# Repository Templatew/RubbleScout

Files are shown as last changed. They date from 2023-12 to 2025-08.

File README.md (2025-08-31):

e

# RubbleScout: *"Navigating Chaos, Saving Lives"*

## Welcome to the Future of Search and Rescue

RubbleScout is a semi-autonomous robot designed to enhance search and rescue operations in disaster-stricken environments by utilizing advanced detection and navigation technologies.

## Project Overview

At this stage, RubbleScout is taking shape both in theory and in practice. 

## Gallery

_ANA2206-Enhanced-NR
_ANA2205-Enhanced-NR
_ANA2209-Enhanced-NR

https://github.com/Templatew/RubbleScout/assets/96289463/7052bb44-568c-42eb-913e-73d9d9e173d0

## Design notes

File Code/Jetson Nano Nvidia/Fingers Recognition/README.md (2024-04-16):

# Integration Guide for Finger Counting Project

## Loading the Jupyter Notebook on Jetson Nano
To initiate the finger counting system, you'll need to start by loading the provided Jupyter Notebook on your Jetson Nano. This notebook contains the necessary code to interface with the pretrained AI model and process the image data in real-time.

Follow these steps to load the notebook:
1. Power on your Jetson Nano and open the terminal.
2. Navigate to the directory containing the Jupyter Notebook.
3. Run the following command to start the Jupyter Notebook server:

`sudo docker run --runtime nvidia -it --rm --network host --volume ~/nvdli-data:/nvdli-nano/data --volume ~/notebooks:/nvdli-nano/notebooks --device /dev/video0 --device /dev/gpiochip0 --privileged nvcr.io/nvidia/dli/dli-nano-ai:v2.0.2-r32.7.1`

4. Open your web browser and enter the URL provided by the Jupyter server to access the notebook.

## Loading the Pretrained AI Model
Once the Jupyter Notebook is up and running, you'll need to load the pretrained AI model `V3.pth` to perform the finger counting. The notebook will have cells dedicated to this task—ensure you execute them to load the model into memory.

## Uploading Code to Arduino Uno
The next step involves uploading the control code to your Arduino Uno. This code is responsible for receiving the finger count and translating it into a binary representation on the LEDs.

To upload the code:
1. Connect your Arduino Uno to your PC via a USB cable.
2. Open the Arduino IDE and load the provided Arduino script.
3. Select the correct board and port from the Tools menu.
4. Click the Upload button to program your Arduino Uno with the script.

## Wiring Schema
A detailed wiring schema is provided in the `wiring` directory. Refer to this schema for connecting the LEDs to your Arduino Uno, and for establishing the I2C communication between the Jetson Nano and Arduino Uno.

Ensure the following connections are made according to the schema:
- Connect SDA and SCL from the Jetson Nano to the corresponding SDA (A4) and SCL (A5) pins on the Arduino Uno.
- Ground connections must be common between both devices.
- If necessary, use pull-up resistors on the SDA and SCL lines, and ensure any required level shifting between 3.3V and 5V logic levels is in place to protect your devices.

After setting up the hardware according to the wiring schema, your system should be ready for a test run. Ensure you follow the instructions closely to avoid any damage to the components due to incorrect wiring or voltage levels.

## Gallery

https://github.com/Templatew/RubbleScout/assets/96289463/1811614b-35ff-42c6-a526-842b8b7e4687

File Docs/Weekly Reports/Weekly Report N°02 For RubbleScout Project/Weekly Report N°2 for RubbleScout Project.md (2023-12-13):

# Weekly Report N°2 for RubbleScout Project
School year 2023-2024

## Project Overview
- **Title:** RubbleScout
- **Tagline:** "Navigating Chaos Saving Lives"
- **Student:** Lorenz CAZAUBON
- **Supervisor:** Pascal MASSON
- **Institution:** Ecole Polytechnique Universitaire de Nice Sophia-Antipolis, Robotics Specialty (Autonomous Systems)
- **Location:** 930 route des Colles, 06410 BIOT France

## Session Activities
- **Lamp Circuit Examination:**
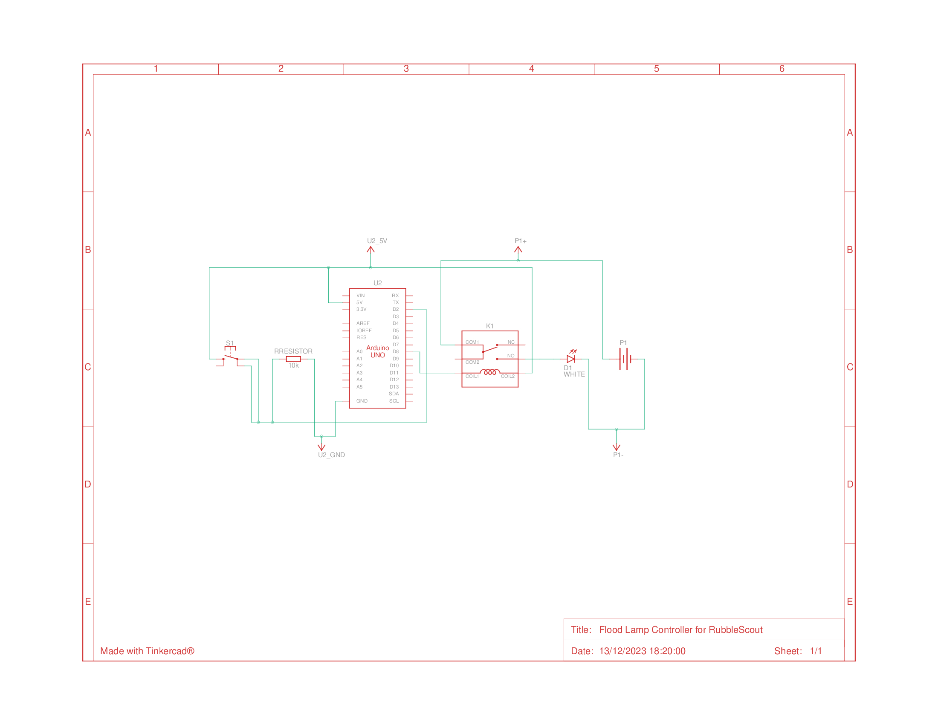
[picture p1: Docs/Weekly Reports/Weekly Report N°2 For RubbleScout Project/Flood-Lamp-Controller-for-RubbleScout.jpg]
  - Detailed review of the circuit powering the lamp. 
  - Identified the inability to vary lamp brightness using PWM due to unknown electronic components.
  - Implemented a relay circuit for on/off functionality without variable brightness.

- **PWM and Lidar Progress:**
  - Spent time seeking a solution for PWM, which was unsuccessful.
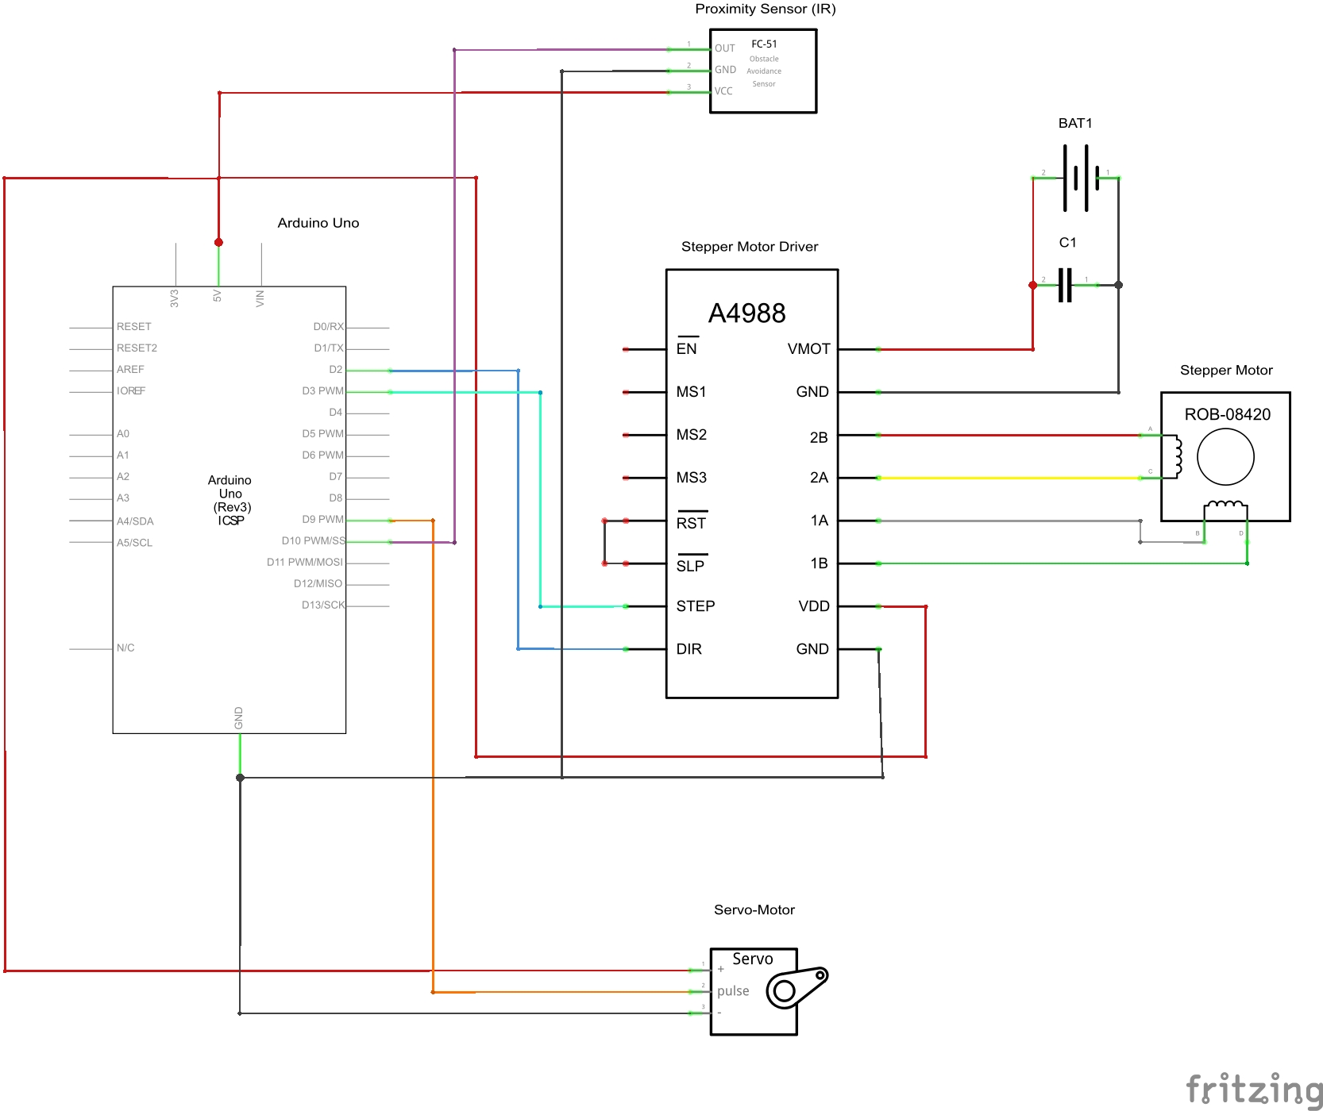
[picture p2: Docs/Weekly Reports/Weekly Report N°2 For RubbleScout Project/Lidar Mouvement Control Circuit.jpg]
Circuit SVG
  - Designed a circuit for controlling the Lidar's movements. 

## Plans for Next Session
- Intend to complete 3D drawings of the Lidar motion controller using CAD software.
- Aim to print and test the parts in the next session.
- Anticipate receiving the robot chassis for starting basic mechanics work.

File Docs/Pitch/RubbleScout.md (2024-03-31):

e
# RubbleScout Project Overview

## Introduction
This document serves as a brief presentation of the RubbleScout robot project for review and assistance from the faculty.

## Student Name
- Lorenz CAZAUBON

## Robot Name
- RubbleScout

## Objective
RubbleScout is designed as a semi-autonomous robotic system aimed at aiding search and rescue operations through 3D environmental scanning and object detection in disaster-stricken areas.

## Technical Synopsis
RubbleScout is built on a tracked platform equipped with a suite of sensors including LiDAR for 3D scanning, ultrasonic for obstacle detection, and cameras for visual input. The core processing unit is an NVIDIA Jetson Nano, which handles data processing and autonomous decision-making, supported by an ESP32 microcontroller for managing sensor integration and actuation.

## State Machine Overview
RubbleScout's software operates on a state machine with states such as Initialization, Standby, Scanning, and Data Transmission. Transitions between states are managed based on sensor inputs and operational modes.

## Hardware & Software Architecture
The robot features a modular architecture allowing for scalability and maintenance. The hardware includes motor drivers, power management, and sensor modules, while the software architecture is designed for real-time processing and modular updates.

### Architecture
- The robot's architecture comprises three primary layers:
  - **Sensing Layer:** LiDAR, ultrasonic sensors, and cameras for environment perception.
  - **Processing Layer:** NVIDIA Jetson Nano for high-level processing and ESP32 for low-level control and sensor integration.
  - **Actuation Layer:** Electric motors for movement and a servo motor for LiDAR scanning.

- [Link to Wiring Diagram](https://github.com/Templatew/RubbleScout/blob/main/Docs/Wiring/ESP32/Schematic_RubbleScout_2024-02-16.pdf)

### Code Overview
The software is developed using C++ on the ESP-IDF framework for real-time operations and Python on the Jetson Nano for data processing and machine learning tasks.

- [Link to Code Documentation](https://github.com/Templatew/RubbleScout/blob/main/Code/Main/README.md)

## Usage of NVIDIA Jetson Nano
- The Jetson Nano serves as the brain of RubbleScout, responsible for processing sensor data, creating 3D maps of the environment, and executing autonomous navigation algorithms. Potential uses also include survivor detection via machine learning and integration with other IoT devices for expanded capabilities.

## Risk Assessment
Identified risks include system malfunctions, electrical failures, and sensor inaccuracies. Mitigation strategies involve redundant design, rigorous testing, and real-time system monitoring.

## Recent Progress
- Successfully conducted the first LiDAR scan with data stored on an SD card.
- Transitioned to ESP-IDF for improved performance.
- Implemented a new DC-DC converter to prevent power issues.

## Supporting Materials
- [Link to the Code Repository](https://github.com/Templatew/RubbleScout/tree/main/Code)
- [Link to the Weekly Reports](https://github.com/Templatew/RubbleScout/tree/main/Docs/Weekly%20Reports)

## **Gallery**

https://github.com/Templatew/RubbleScout/assets/96289463/867a7651-68fa-45cb-8242-6cb173693c5a

https://github.com/Templatew/RubbleScout/assets/96289463/f9fa39b1-5d0c-4065-bb0d-41c5539a41e1

https://github.com/Templatew/RubbleScout/assets/96289463/a6dde0ae-bb52-4444-9256-39dd32141298

*This presentation is for academic review purposes*

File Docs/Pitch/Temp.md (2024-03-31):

# RubbleScout Project Presentation

## Student Name
- Lorenz Cazaubon

## Robot Name
- RubbleScout

## Objective of the Robot
- The primary objective of RubbleScout is to provide a semi-autonomous robotic solution for search and rescue operations within disaster-struck environments. RubbleScout is designed to navigate through rubble and challenging terrains, identify survivors, and provide real-time data to rescue teams, thereby enhancing the safety and efficiency of rescue missions.

## Technical Elements
### System Synopsis
- RubbleScout is built on a robust tracked platform, allowing for stable movement across varied terrains. The core of the system is the ESP32 microcontroller for control and the NVIDIA Jetson Nano for advanced processing tasks such as sensor data analysis and autonomous decision-making.

### State Machine
- The robot operates in several states:
  - **Idle:** Waiting for commands.
  - **Manual Control:** Direct control through user input.
  - **Auto Navigation:** Autonomous movement and obstacle avoidance. *(Not ready yet)*
  - **Scan Mode:** LiDAR-based 3D environment mapping.
  - **Data Transmission:** Sending collected data to the base station.
  
### Architecture
- The robot's architecture comprises three primary layers:
  - **Sensing Layer:** LiDAR, ultrasonic sensors, and cameras for environment perception.
  - **Processing Layer:** NVIDIA Jetson Nano for high-level processing and ESP32 for low-level control and sensor integration.
  - **Actuation Layer:** Electric motors for movement and a servo motor for LiDAR scanning.

### Code Overview
- The software is developed using C++ on the ESP-IDF framework for real-time operations and Python on the Jetson Nano for data processing and machine learning tasks.
More about the code [here](https://github.com/Templatew/RubbleScout/tree/main/Code)

## Usage of NVIDIA Jetson Nano
- The Jetson Nano serves as the brain of RubbleScout, responsible for processing sensor data, creating 3D maps of the environment, and executing autonomous navigation algorithms. Potential uses also include survivor detection via machine learning and integration with other IoT devices for expanded capabilities.

## **Gallery**

https://github.com/Templatew/RubbleScout/assets/96289463/867a7651-68fa-45cb-8242-6cb173693c5a

https://github.com/Templatew/RubbleScout/assets/96289463/f9fa39b1-5d0c-4065-bb0d-41c5539a41e1

https://github.com/Templatew/RubbleScout/assets/96289463/a6dde0ae-bb52-4444-9256-39dd32141298

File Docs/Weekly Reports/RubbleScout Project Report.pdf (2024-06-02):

Robotics,
Autonomous systems

# RubbleScout Project Report

School year 2023-2024

RubbleScout,

## "Navigating Chaos, Saving Lives"

## Student: Lorenz CAZAUBON

## Supervisor: Pascal MASSON

Polytech Nice Sophia, robotics speciality (autonomous systems)

930 route des Colles, 06410 BIOT, France

## Table of Content

1. Introduction | 2
2. Architecture | 3
3. Algorithm | 4
4. Project Cost | 4
5. Issues and Solutions | 5
6. Conclusion and Future Work | 5
7. Appendix | 7

### 1. Introduction

RubbleScout is a semi-autonomous robot designed to enhance search and rescue operations in disaster-stricken environments. The primary goal is to reduce risks for rescuers and speed up interventions by providing accurate data on affected environments.

Project Goals:

- Reduce Risks: Minimise the exposure of rescuers to dangerous and unstable conditions.
- Accelerate Interventions: Improve the efficiency and speed of search and rescue operations.
- Provide Accurate Data: Offer precise and reliable information about the disaster area to aid in decision-making.

Main Applications:

- 3D Mapping: Create detailed maps of disaster-stricken areas to assist in navigation and planning.
- Obstacle and Survivor Detection: Identify obstacles and detect survivors in the debris to facilitate rescue efforts.

### 2. Architecture

The following schematic illustrates the overall architecture and key components of the RubbleScout project. The system is centered around the ESP32 microcontroller, which interfaces with various sensors and actuators to perform the necessary functions. For detailed wiring connections, please refer to the appendix.

Main Components:

ESP32: The central microcontroller responsible for processing data and controlling the system.
Lidar + Servo and Stepper Motor: Used for distance measurement and 3D mapping. Jetson Nano + Camera: Planned for future implementation, responsible for advanced processing tasks like video streaming and object recognition.
SD Card Reader: Data logging.

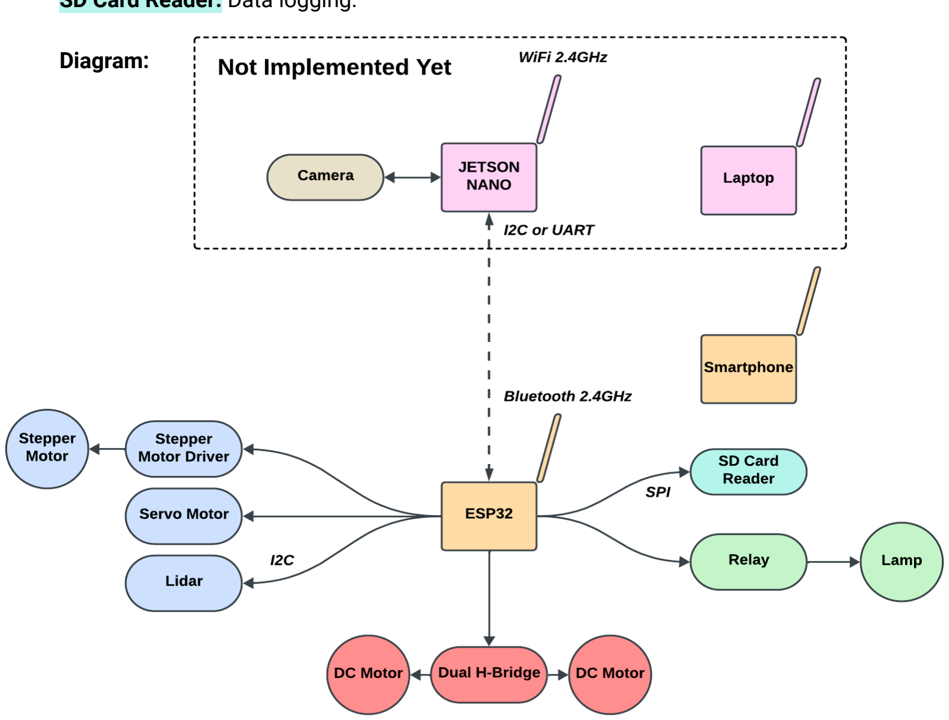
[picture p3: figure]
Diagram:

Note: The complete wiring schematic is included in the appendix for further reference.

### 3. Algorithm

The functionality is divided into different tasks managed by the ESP32 microcontroller.

The state machine for RubbleScout defines the different operational states of the robot and the transitions between these states.

This simplified diagram provides an overview of the key states and transitions:

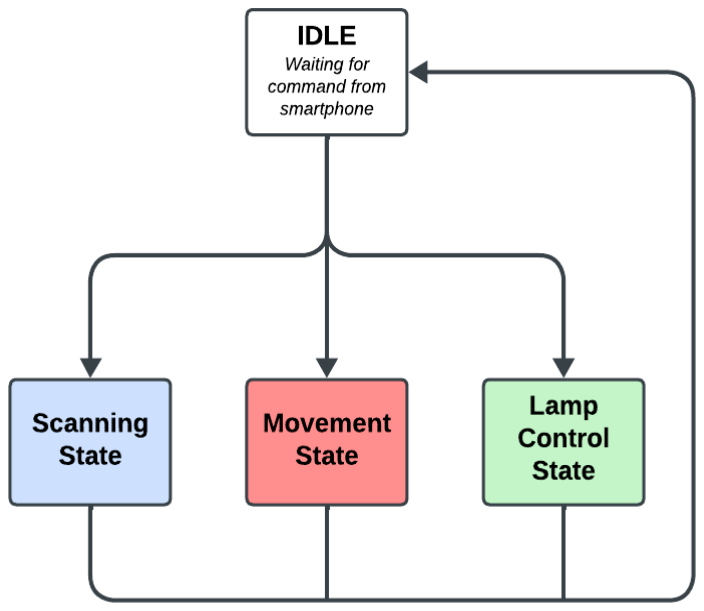
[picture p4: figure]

Note: The complete state machine diagram is included in the appendix.

### 4. Project Cost

In total I worked around 200 hours on the project (including 72 hours in the project session), and at an hourly rate of 23.75€, that works out at 4 750€ for the labour involved.

The total estimated cost is therefore 6 000€.

Component | Cost (€)
3D Scan Module | 430
Chassis + Motors | 180
Jetson + Camera | 290
ESP32 + SD | 40
Battery + Buck | 70
Lamp + Relay | 30
Building Materials | 120
Miscellaneous | 90
Total | 1 250

### 5. Issues and Solutions

Problem:
Power Supply Overload
Solution:
Replaced the LDO with a Buck Converter, which is more efficient and capable of handling higher power loads without overheating.

Problem:
The Arduino Uno microcontroller was unable to handle the computational demands of the project, particularly for the 3D scanning task which required more processing power and memory.
Solution:
Upgraded to an ESP32 microcontroller, which offers dual-core processing, integrated Bluetooth and Wi-Fi, and greater speed and memory capacity.

Problem:
The initial code implementation was too slow, causing delays in data processing and system responsiveness.
Solution:
Implemented multithreading using the ESP-IDF (Espressif IoT Development Framework) to run tasks in parallel, significantly improving the speed and efficiency of the system.

### 6. Conclusion and Future Work

RubbleScout has successfully achieved several key milestones:

3D Scanning: The system can perform 3D scans of its environment using Lidar, servo motors, and stepper motors. The data collected is stored on an SD card for further analysis.
Basic Movement: The robot can be controlled via a smartphone using Bluetooth, allowing for precise movement control.
Lamp Control: The system includes a relay-controlled lamp, which can be turned on and off remotely to provide illumination in dark environments.

However, some aspects of the project are still in development:

Jetson Nano Integration: The advanced computational capabilities of the Jetson Nano, such as video streaming, object recognition, and autonomous navigation, have not been fully implemented.

Future Work

To fully realize the potential of RubbleScout, the following developments are planned:

Integration of Jetson Nano:

-Implement video streaming and real-time processing for object and person recognition.
-Develop and integrate advanced navigation algorithms to enable autonomous operation.

Addition of New Sensors:

Integrate additional sensors such as temperature, gas, and humidity sensors to provide more comprehensive environmental data.

Long-Range Communication:

Implement long-range communication protocols (e.g., ELRS, CROSSFIRE) to extend the operational range of the robot in disaster-stricken areas.

Robustness and Durability:

Enhance the physical design of the robot to withstand harsh conditions in disaster environments, including shock absorption and waterproofing.

Conclusion:

RubbleScout represents a significant step forward in improving search and rescue operations. With further development and enhancements, it has the potential to become a vital tool for rescuers, providing them with the necessary data and capabilities to save lives more effectively and safely.

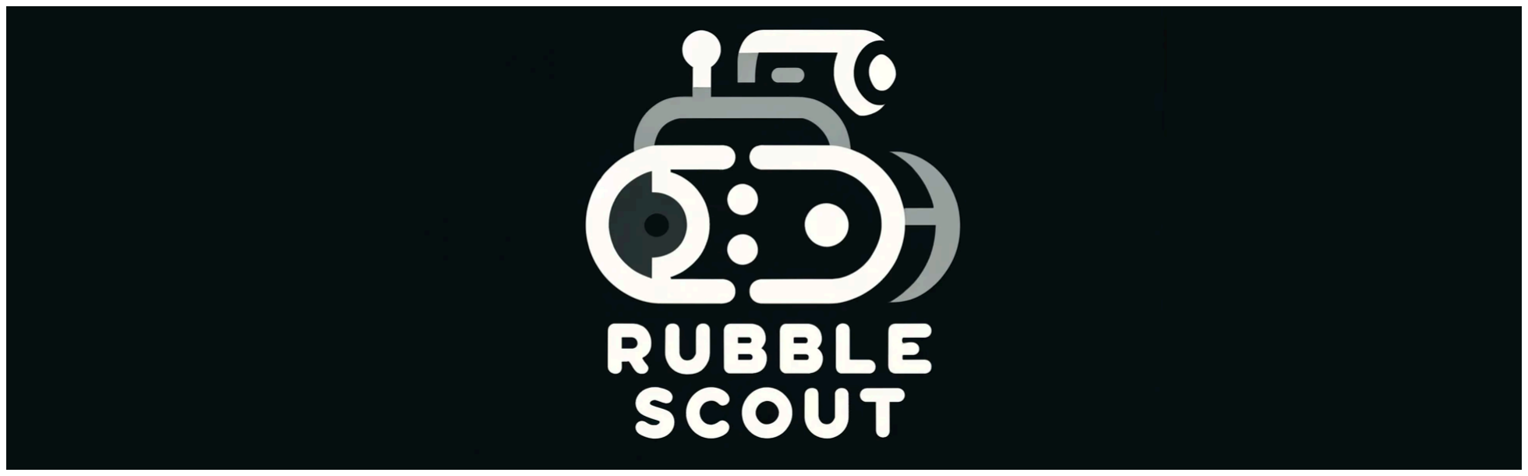
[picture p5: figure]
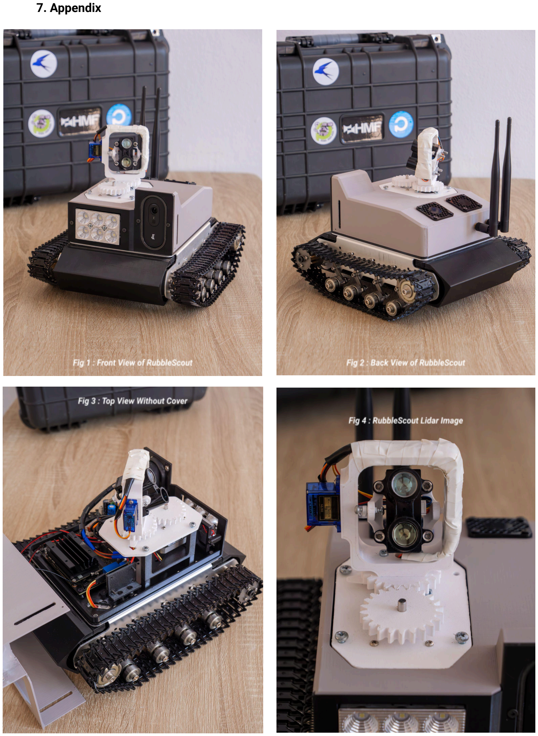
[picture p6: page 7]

### 7. Appendix

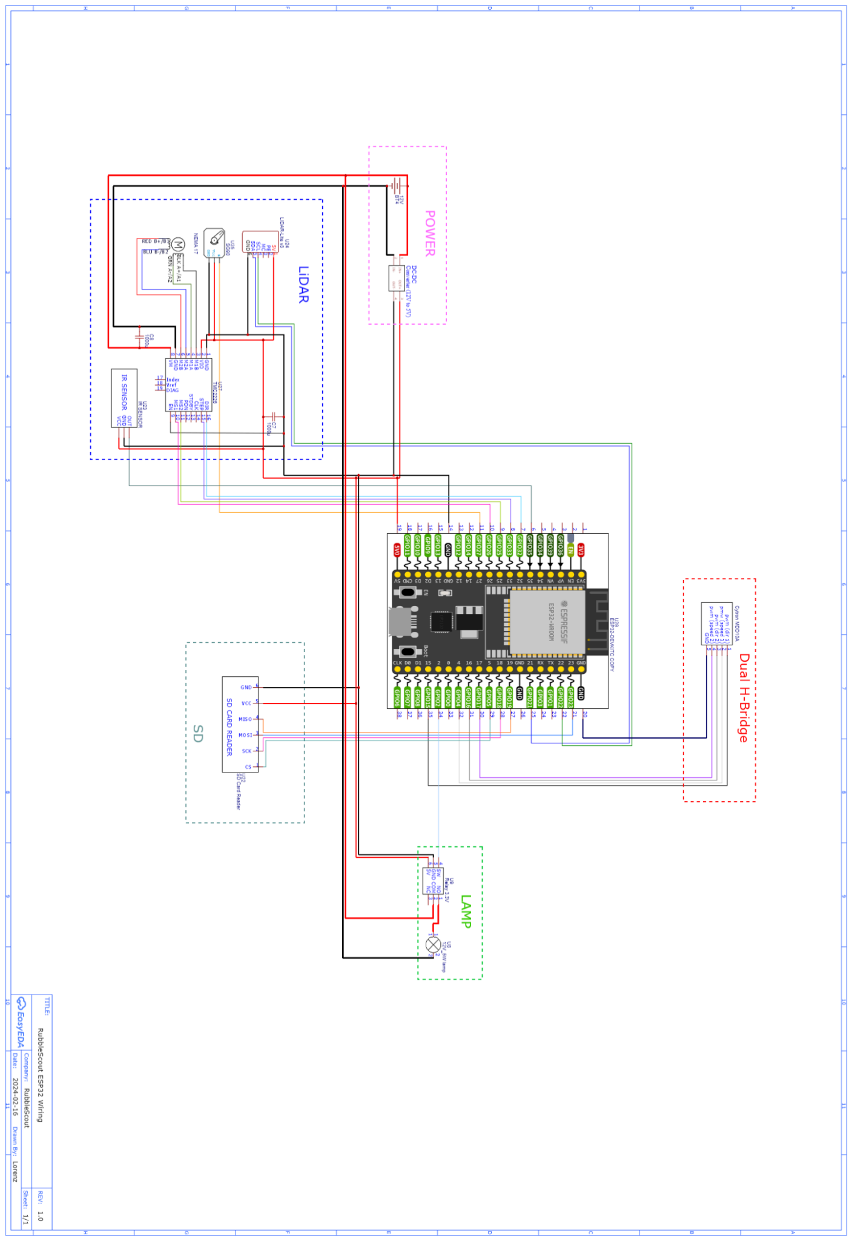
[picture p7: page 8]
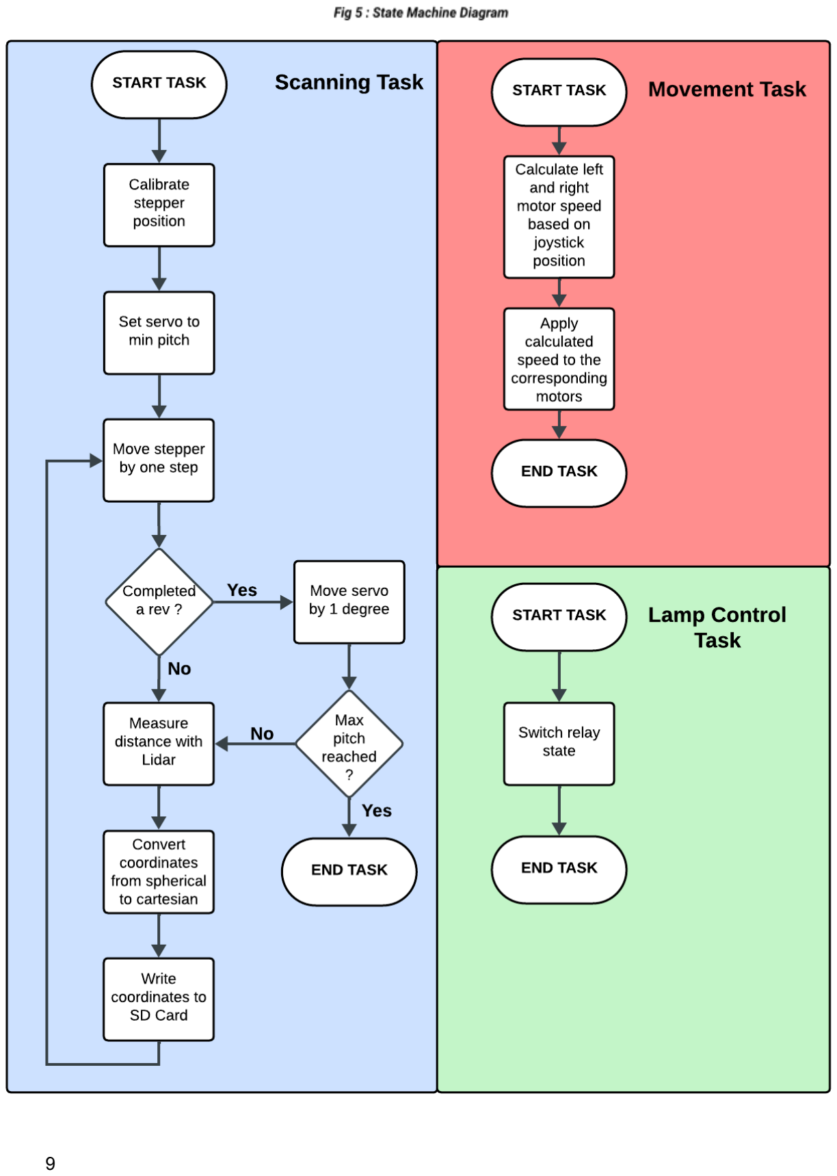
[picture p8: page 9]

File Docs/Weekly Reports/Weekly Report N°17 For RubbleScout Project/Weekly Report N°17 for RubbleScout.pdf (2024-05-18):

Robotics,

### Autonomous systems

# Weekly Report N°17 for

### School year 2023-2024

RubbleScout,

## "Navigating Chaos, Saving Lives"

## Student: Lorenz CAZAUBON

## Supervisor: Pascal MASSON

Ecole Polytechnique Universitaire de Nice Sophia-Antipolis, robotics speciality (autonomous systems)

930 route des Colles, 06410 BIOT, France

Objectives:

- Complete the design of new 3D parts in the CAD software for the updated RubbleScout robot assembly.

Activities Undertaken:

### 1. Completion of CAD Design:

- Finished designing all the new 3D parts in the CAD software, integrating the new functionalities and components:
- NVIDIA Jetson Nano mount
- multiple 40 mm fan housing for improved cooling
- PETG-based battery protection
- Reinforced wire connections for the ESP
- Mount for the Logitech C505e camera
- 12V lamp housing with relay control
- Aesthetic magnetic covers and other enhancements

### 2. Review and Refinement:

- Conducted a thorough review of the CAD designs to ensure all components fit together seamlessly.
- Made adjustments to optimize the layout and functionality, ensuring ease of assembly and maintenance.

Results and Observations:

- Design Completion: Successfully completed the CAD design phase, creating detailed models for all new parts.
- Enhanced Integration: The designs effectively incorporate the new components, promising improved performance, safety, and aesthetics for the RubbleScout robot.
- Preparations for Prototyping: The detailed CAD models are now ready for the next phase, which involves 3D printing and physical testing.

Next Steps:

- 3D Printing: Begin the process of 3D printing the newly designed parts.
- Test Fit and Assembly: Once printed, test fit all parts to ensure proper alignment and functionality.
- Iterative Refinement: Based on the test fitting results, make any necessary adjustments to the CAD models and reprint as needed.

2

Reflections:

This session marks a significant milestone in the redesign of RubbleScout, transitioning from conceptual planning to tangible design completion. The detailed CAD models set the stage for the next phase of development, where physical testing will validate the improvements and guide further refinements. The anticipation of seeing these new parts come to life and integrating them into the robot is high, as it promises to bring substantial advancements in RubbleScout's capabilities and usability.

3

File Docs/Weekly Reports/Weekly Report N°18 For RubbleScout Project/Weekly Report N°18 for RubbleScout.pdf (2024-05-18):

Robotics,

### Autonomous systems

# Weekly Report N°18 for

### School year 2023-2024

RubbleScout,

## "Navigating Chaos, Saving Lives"

## Student: Lorenz CAZAUBON

## Supervisor: Pascal MASSON

Ecole Polytechnique Universitaire de Nice Sophia-Antipolis, robotics speciality (autonomous systems)

930 route des Colles, 06410 BIOT, France

Objectives:

- Test fit the newly printed 3D parts for the RubbleScout robot.
- Identify necessary adjustments to the parts for enhanced functionality.

Activities Undertaken:

### 1. Test Fitting of 3D Printed Parts:

- Assembled the newly printed 3D components, including mounts for the NVIDIA Jetson Nano, the camera, and the lamp, along with the battery protection and magnetic covers.
- Evaluated the fit and alignment of each part within the robot's chassis.

### 2. Identification of Adjustments:

- Noted the need for modifications such as:
- Drilling proper holes for antenna integration to improve communication range.

Results and Observations:

- Fit and Function: Most parts fit well, but a few require adjustments for optimal functionality and integration.
- Cooling Requirements: The need for additional cooling for the lamp was identified during the test, prompting the decision to add a 40mm fan to this component.

Next Steps:

- CAD Adjustments: Update the CAD designs to incorporate the identified modifications, such as antenna holes and correct fan sizes.
- Reprint and Retest: Print the modified parts and conduct another test fit session to ensure all adjustments meet the project's requirements
- Develop Control Software: Begin coding a comprehensive control interface that allows user interaction with all robot functionalities, focusing initially on manual controls.
- Plan for Autonomous Functionality: Outline the steps necessary to implement autonomous operations, which will likely involve integrating sensor data with decision-making algorithms.

2

Reflections:

This session was crucial for validating the physical aspects of the latest design updates. The insights gained from test fitting are invaluable, directing specific modifications that will enhance the overall functionality and reliability of RubbleScout. Looking ahead, the focus will shift towards developing a user-friendly control interface, which will be a significant step towards achieving a fully operational prototype. The subsequent challenge will be to tackle the autonomous capabilities of the robot, marking a pivotal phase in the project that will test the integration of hardware and software to achieve independent operation.

3

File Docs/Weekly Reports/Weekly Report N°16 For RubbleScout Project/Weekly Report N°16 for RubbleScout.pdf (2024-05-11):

Robotics,

### Autonomous systems

# Weekly Report N°16 for

### School year 2023-2024

RubbleScout,

## "Navigating Chaos, Saving Lives"

## Student: Lorenz CAZAUBON

## Supervisor: Pascal MASSON

Ecole Polytechnique Universitaire de Nice Sophia-Antipolis, robotics speciality (autonomous systems)

930 route des Colles, 06410 BIOT, France

Objectives:

- Redesign the CAD assembly of the RubbleScout robot.
- Integrate new components and functionalities to enhance performance and aesthetics.

Activities Undertaken:

### 1. CAD Redesign Planning:

- Initiated a comprehensive redesign of the RubbleScout's CAD assembly to incorporate new components and functionalities.
- Mapped out the integration points and spatial arrangements for the new additions to ensure a seamless design transition.

### 2. Component Integration Planning:

- NVIDIA Jetson Nano: Designated as the new processing unit to enhance the robot's AI and computing capabilities.
- 80 mm Fan: Integrated into the design for improved heat management, essential for maintaining optimal operation of the Jetson Nano and other electronics.
- Battery Protection: Developed a concept for a basic puncture protection system using PETG to safeguard the battery unit.
- Robust Wiring Connections: Planned enhancements to the electrical connections, specifically for the ESP, to prevent disconnections during operation
- Camera and Lamp Installation: Outlined positions for a Logitech C505e camera and a 12V lamp, including a relay for controlling the lamp, enhancing the robot's vision and operational capabilities in low-light conditions.
- Aesthetic Features: Considered the addition of magnetic covers and other aesthetic elements to provide easy access to internal components while maintaining a sleek, functional appearance.

Results and Observations:

- Clear Design Direction: Although the physical CAD work is in its early stages, a solid plan is in place for the systematic integration of new components.
- Enhanced Functionality and Safety: The planned additions, such as the Jetson Nano and battery protection, are set to significantly boost the robot’s performance and safety.
- Aesthetics and Accessibility: The incorporation of magnetic covers will not only enhance the robot's appearance but also improve accessibility for maintenance and upgrades.

2

Next Steps:

- Detailed CAD Development: Begin the detailed CAD work based on the initial plans, focusing on precise placement and mounting solutions for all new components.
- Prototype Testing: Once the CAD redesign is sufficiently advanced, prototype the new assembly to test fit, function, and the interaction of components.
- Iterative Design Improvements: Use feedback from initial prototyping to refine the CAD design, ensuring all new functionalities operate as intended and aesthetic elements align with practical requirements.

Reflections:

This session marked a pivotal shift towards a more robust and functional design of the RubbleScout robot, integrating cutting-edge technology and user-centric features. The thoughtful planning and initial redesign efforts lay a strong foundation for the next phase of development, promising a significantly enhanced robotic platform that is as practical as it is visually appealing. The upcoming CAD work and prototyping are anticipated with enthusiasm, as they will bring the conceptual improvements to tangible reality.

3

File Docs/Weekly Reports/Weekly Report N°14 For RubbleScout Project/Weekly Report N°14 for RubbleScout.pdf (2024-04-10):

Robotics,

### Autonomous systems

# Weekly Report N°14 for

### School year 2023-2024

RubbleScout,

## "Navigating Chaos, Saving Lives"

## Student: Lorenz CAZAUBON

## Supervisor: Pascal MASSON

Ecole Polytechnique Universitaire de Nice Sophia-Antipolis, robotics speciality (autonomous systems)

930 route des Colles, 06410 BIOT, France

Objectives:

- Begin the exploration of NVIDIA Jetson Nano capabilities.
- Experiment with AI models using a camera module.

Activities Undertaken:

### 1. Jetson Nano Setup:

- Initialized the Jetson Nano development kit, setting up the necessary operating system and drivers.
- Familiarized with the software environment and available resources/documentation provided by NVIDIA.

### 2. AI Experimentation:

- Connected a camera module to the Jetson Nano and ran sample AI programs to gauge the processing capabilities.
- Explored basic object detection and image processing functionalities as preliminary tests for potential search and rescue applications.

Results and Observations:

- Jetson Nano Familiarization: Successfully set up the Jetson Nano and began exploring its extensive AI capabilities, noting the ease of use and powerful processing potential.
- AI Model Testing: Initial AI tests with the camera module demonstrated the Jetson Nano's ability to handle real-time data analysis, a promising feature for integrating AI into RubbleScout's systems.

Next Steps:

- Deep Learning Integration: Plan more advanced tests using deep learning models tailored for object recognition and environmental analysis relevant to search and rescue scenarios.
- Real-World Testing: Implement the AI functionalities in more practical, real-world conditions to test their reliability and accuracy.
- Performance Benchmarking: Assess the Jetson Nano's performance benchmarks in various operational settings to ensure it meets the project's requirements.

Reflections:

This session marked the beginning of a pivotal phase in the RubbleScout project, delving into the capabilities of the NVIDIA Jetson Nano. The potential to enhance RubbleScout with AI-driven features promises a significant leap forward in its development. As the project moves into more complex AI implementations, the insights gained from this session will serve as a valuable foundation for future advancements.

2

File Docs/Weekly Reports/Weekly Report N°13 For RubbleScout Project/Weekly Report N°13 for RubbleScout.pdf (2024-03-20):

Robotics,

### Autonomous systems

# Weekly Report N°13 for

### School year 2023-2024

RubbleScout,

## "Navigating Chaos, Saving Lives"

## Student: Lorenz CAZAUBON

## Supervisor: Pascal MASSON

Ecole Polytechnique Universitaire de Nice Sophia-Antipolis, robotics speciality (autonomous systems)

930 route des Colles, 06410 BIOT, France

Unfortunately during this session I wasn't able to make any progress on the RubbleScout project, as over the last few days I've been helping the Hirondelle project, which I'm also part of, to get a decent prototype ready for the final of the 'young start-up challenge' (Challenge Jeunes Pousses) organised by Telecom Valley. For this project, I've mainly been doing assembly, wiring, soldering and a bit of coding so that my mates could work on the oral presentation and not worry about the prototype.

I'm going to try to catch up with the big delay I've had over the next few days, and I'm probably going to start working on the idea of local data processing using a nvidia jetson nano card.

2

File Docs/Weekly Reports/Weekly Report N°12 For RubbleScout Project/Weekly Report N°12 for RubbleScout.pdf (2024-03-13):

Robotics,

### Autonomous systems

# Weekly Report N°12 for

### School year 2023-2024

RubbleScout,

## "Navigating Chaos, Saving Lives"

## Student: Lorenz CAZAUBON

## Supervisor: Pascal MASSON

Ecole Polytechnique Universitaire de Nice Sophia-Antipolis, robotics speciality (autonomous systems)

930 route des Colles, 06410 BIOT, France

Objectives:

- Design and 3D print a protective component for the battery situated on the underside of the robot.
- Enhance cable management through strategic rewiring.
- Advance the transition from the Arduino framework to ESP-IDF for the project's coding environment.

Activities Undertaken:

### 1. Battery Protection Design:

- Engineered and 3D printed a custom part tailored to secure and safeguard the battery, crucial for the robot's power supply, while ensuring it fits seamlessly into the "belly" of RubbleScout.

### 2. Cable Management Optimization:

- Reworked and tidied up the wiring to enhance the organization and functionality of the internal components, focusing on creating a streamlined and efficient layout that facilitates maintenance and reduces the risk of damage.

### 3. Framework Transition Progress:

- Made substantial strides in migrating the codebase from the Arduino framework to the more robust and feature-rich ESP-IDF, setting a solid foundation for advanced development and operational capabilities.

Results and Observations:

- Battery Component: The newly designed protective part for the battery has been successfully integrated, providing essential protection and stability to the power source, thus enhancing the overall durability of RubbleScout.
- Improved Cable Organization: The restructured cabling has not only improved the internal aesthetics but also the robot's operational reliability, ensuring clear and safe connections between components.
- Framework Migration: The ongoing transition to ESP-IDF is proving to be promising, with early indications suggesting a potential for increased efficiency, better resource management, and greater flexibility in programming.

2

Next Steps:

- Testing and Validation: Conduct thorough tests to assess the effectiveness of the new battery protection and the reorganized cabling, ensuring they meet the project's standards for safety and functionality.
- Continued ESP-IDF Integration: Persist with the diligent work of adapting the project's code to the ESP-IDF environment, focusing on leveraging its advanced features to enhance RubbleScout's performance.
- Documentation and Review: Document the changes and improvements made during this session for future reference and conduct a review to identify any areas needing further attention or optimization.

Reflections:

This session was instrumental in fortifying RubbleScout's physical and technical infrastructure. The addition of a custom-designed battery protection component and the optimization of cable management significantly contribute to the robot's resilience and operational efficiency. Meanwhile, the transition to ESP-IDF is a strategic move toward unlocking new potentials in programming flexibility and performance enhancement. These advancements are crucial steps toward realizing RubbleScout's mission of navigating chaos and saving lives more effectively.

3

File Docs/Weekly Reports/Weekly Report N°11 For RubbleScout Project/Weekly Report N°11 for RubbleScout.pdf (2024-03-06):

Robotics,

### Autonomous systems

# Weekly Report N°11 for

### School year 2023-2024

RubbleScout,

## "Navigating Chaos, Saving Lives"

## Student: Lorenz CAZAUBON

## Supervisor: Pascal MASSON

Ecole Polytechnique Universitaire de Nice Sophia-Antipolis, robotics speciality (autonomous systems)

930 route des Colles, 06410 BIOT, France

Objectives:

- Upgrade the mounting for electronic components from wood to PMMA (Polymethyl Methacrylate) plate for increased durability and reliability.
- Replace the malfunctioning LiDAR unit.
- Improve the wiring circuit with a more robust DC-DC converter to enhance system stability and prevent future failures.

Activities Undertaken:

### 1. Electronics Mounting Upgrade:

- Substituted the wood plank with a PMMA plate to mount the electronics, offering better support and resilience for the components.

### 2. LiDAR Replacement:

- Installed a new LiDAR unit to replace the one that previously failed, ensuring the core functionality of RubbleScout's navigation and mapping capabilities is maintained.

### 3. Circuitry Enhancement:

- Reconfigured the wiring layout and incorporated a sturdier DC-DC converter into the circuit. This change is aimed at providing a more reliable power supply and minimizing the risk of electrical issues.

Results and Observations:

- Mounting Stability: The transition to a PMMA plate for electronics mounting has significantly improved the structural integrity of the component setup, promising enhanced durability in various operational conditions.
- LiDAR Operational Efficiency: With the replacement of the LiDAR, initial tests show the unit is functioning well, reinstating the robot's ability to perform detailed environmental scans.
- Power Supply Reliability: The new DC-DC converter has fortified the power system, providing a more stable and reliable energy supply to all components, which should mitigate the risk of similar electrical mishaps in the future.

2

Next Steps:

- System Integration Testing: Conduct comprehensive tests to ensure all newly installed components and reconfigured systems work cohesively and without fault.
- Performance Evaluation: Assess the operational improvements brought about by the hardware upgrades, particularly focusing on the efficiency and reliability of the LiDAR scanning process.
- Continual Monitoring: Keep a close watch on the power system's performance during extended operation periods to verify the effectiveness of the new DC-DC converter and identify any areas for further improvement.

Reflections:

This session was pivotal in reinforcing RubbleScout's hardware foundation, setting a new standard for its build quality and operational reliability. Upgrading to a PMMA mounting plate, replacing the LiDAR, and enhancing the power circuitry are critical steps in ensuring the robot's durability and functionality. As we move forward, these improvements will be crucial in enabling RubbleScout to navigate and map environments more effectively, bringing us closer to our goal of creating a dependable robotic aid for search and rescue operations.

3

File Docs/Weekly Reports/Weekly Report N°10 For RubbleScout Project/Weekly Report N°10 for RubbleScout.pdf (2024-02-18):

Robotics,

### Autonomous systems

# Weekly Report N°10 for

### School year 2023-2024

RubbleScout,

## "Navigating Chaos, Saving Lives"

## Student: Lorenz CAZAUBON

## Supervisor: Pascal MASSON

Ecole Polytechnique Universitaire de Nice Sophia-Antipolis, robotics speciality (autonomous systems)

930 route des Colles, 06410 BIOT, France

Objectives:

- Conduct the first complete LiDAR scan using the ESP32.
- Evaluate the performance and identify areas for improvement.

Activities Undertaken:

### 1. First Complete LiDAR Scan:

- Successfully executed the initial full-scale LiDAR scan with the ESP32, marking a significant milestone in the project's development.
- The scan results were promising, providing a solid foundation for further optimization. Exemples are available in the github folder.

### 2. Performance Assessment:

- The LiDAR system achieved a scanning frequency of 50Hz, which, while functional, falls short of the 500Hz capability advertised by the manufacturer, Garmin.
- This discrepancy led to the decision to transition the development framework to ESP-IDF, aiming to harness its lower-level control for enhanced performance.

### 3. Hardware Troubleshooting:

- Encountered a malfunction in the 5V power rail, necessitating a thorough system check to diagnose and repair the fault, and to assess any potential damage to other components.

Results and Observations:

- LiDAR Scan Quality: The quality of the LiDAR scan was commendable for a first attempt, offering valuable insights into the environmental mapping capabilities of RubbleScout.
- Technical Limitations: The current scanning rate limitation highlights a critical area for technical improvement, necessitating a framework switch to unlock the full potential of the hardware.
- Hardware Reliability: The issue with the 5V rail underscores the importance of robust system design and the need for regular maintenance checks to ensure system integrity.

Next Steps:

- Framework Transition: Initiate the migration to the ESP-IDF framework, focusing on optimizing the code to achieve higher LiDAR scanning frequencies.
- System Repair and Testing: Reconstruct the affected system components, replace the faulty 5V rail, and conduct comprehensive tests to ensure no other parts were compromised.
- Performance Optimization: Analyze the initial scan data to refine the scanning process, aiming for higher accuracy and efficiency in subsequent tests.

2

Reflections:

This session was a blend of significant achievements and unforeseen challenges. Completing the first LiDAR scan with the ESP32 is a testament to the project's progress, offering a glimpse into its potential capabilities. The shift to ESP-IDF represents a strategic pivot towards leveraging more advanced technical solutions to overcome current limitations. The hardware issue, while a setback, provides a learning opportunity to enhance the system's durability and reliability. As RubbleScout continues to evolve, each session brings us closer to realizing its full potential in real-world applications.

3

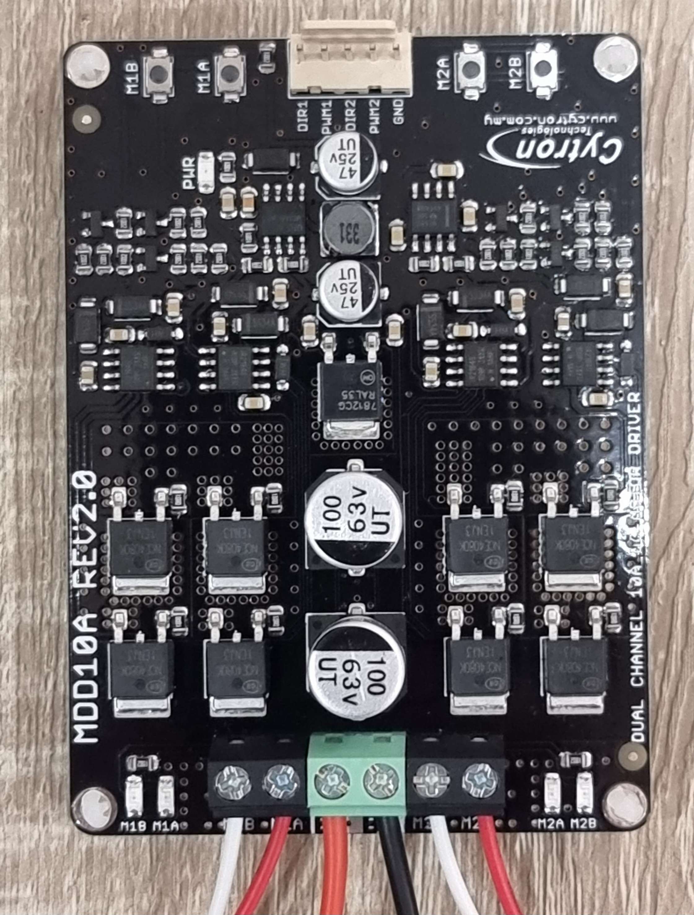
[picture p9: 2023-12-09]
Docs/Weekly Reports/Weekly Report N°03 For RubbleScout Project/DC Motor Driver.jpg

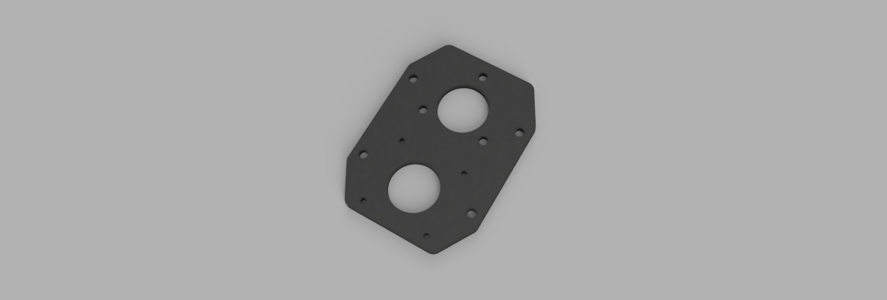
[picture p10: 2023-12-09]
Docs/Weekly Reports/Weekly Report N°03 For RubbleScout Project/Main_Part.png

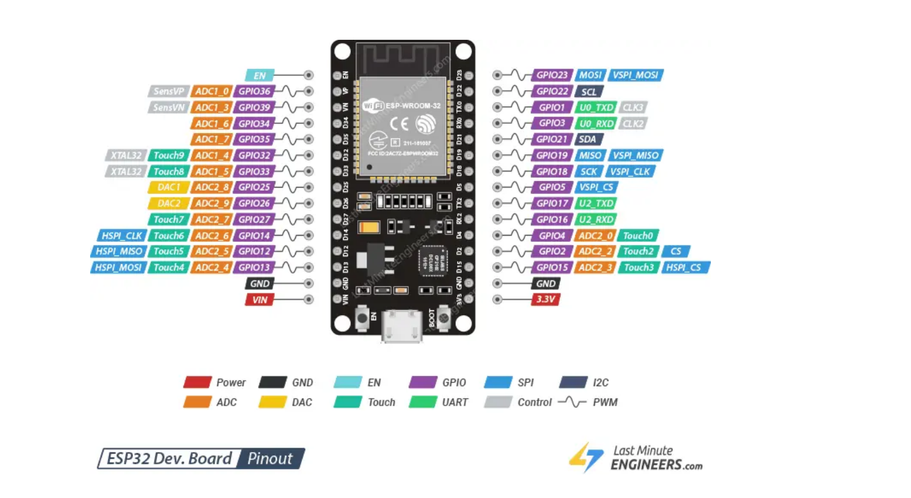
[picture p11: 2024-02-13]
Docs/Hardware/ESP32/ESP32.png

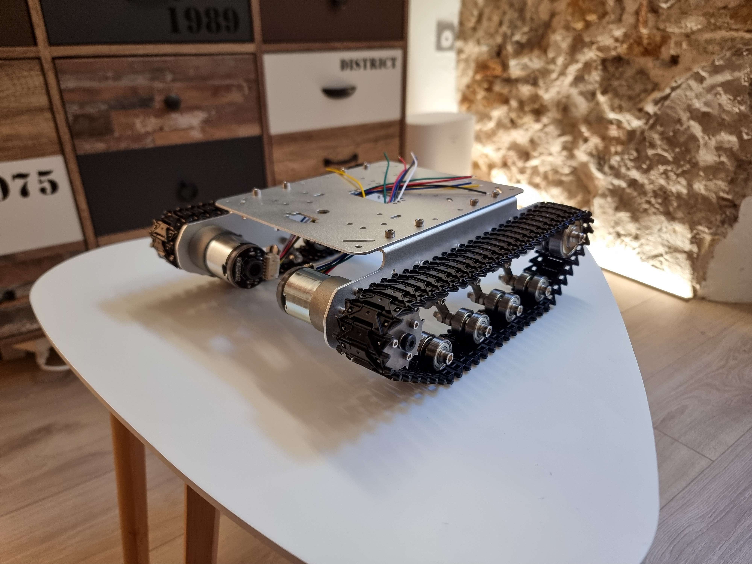
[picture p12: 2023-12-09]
Docs/Weekly Reports/Weekly Report N°03 For RubbleScout Project/Tracked Chassis.jpg

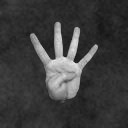
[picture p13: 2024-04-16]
Code/Jetson Nano Nvidia/Fingers Recognition/images/L4.jpg

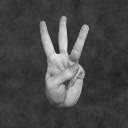
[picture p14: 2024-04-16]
Code/Jetson Nano Nvidia/Fingers Recognition/images/L3.jpg

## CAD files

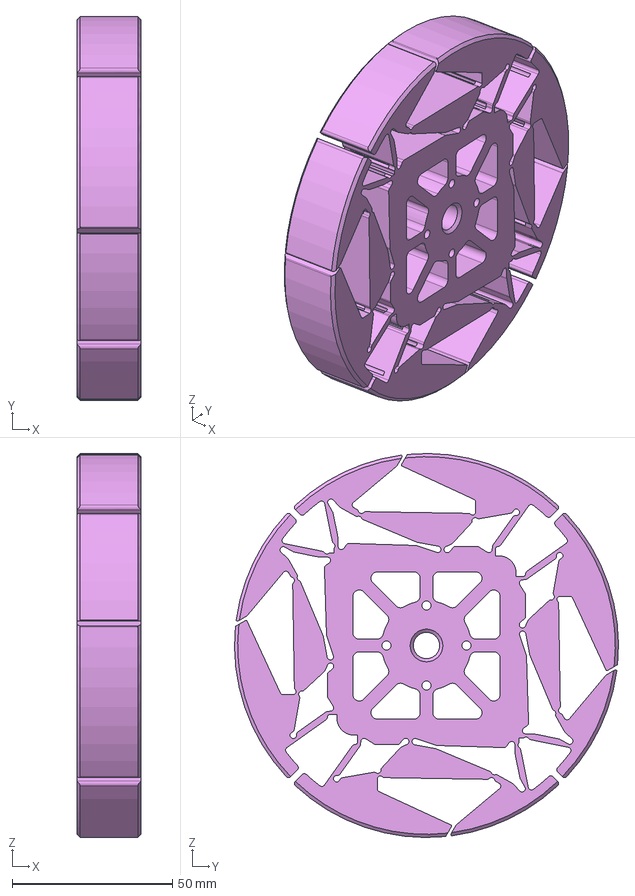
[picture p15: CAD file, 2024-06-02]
Docs/CAD/New Hybrid - Part 1.step
20.0 x 120.0 x 120.0 mm

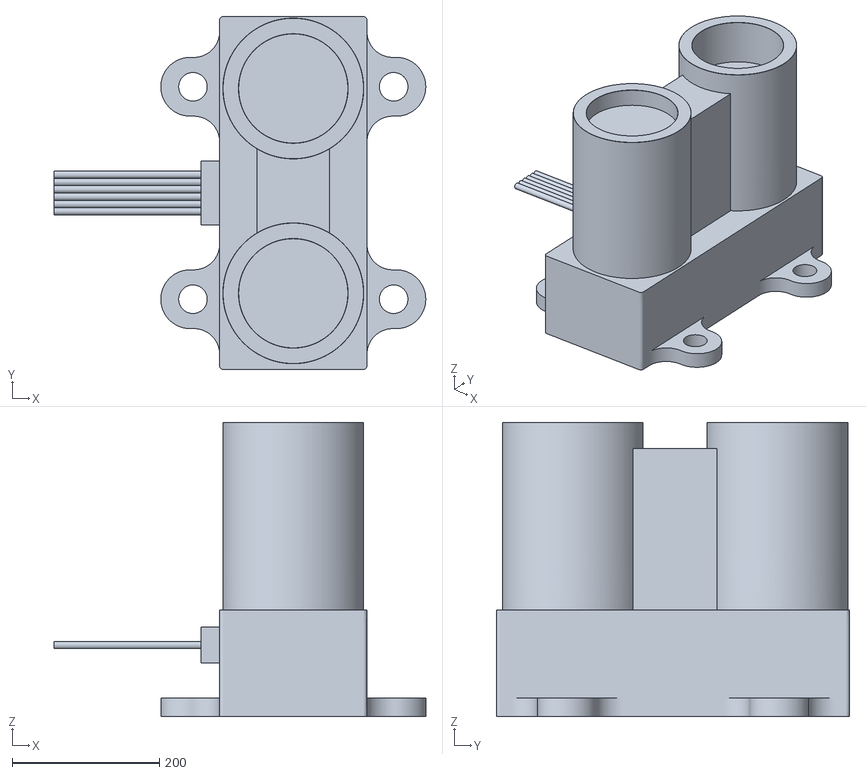
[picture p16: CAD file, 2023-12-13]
Docs/Weekly Reports/Weekly Report N°03 For RubbleScout Project/Lidar_Lite_V3 v2.stl
505.5 x 480.2 x 400.4

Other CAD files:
Docs/CAD/New Hybrid - Part 1.stl

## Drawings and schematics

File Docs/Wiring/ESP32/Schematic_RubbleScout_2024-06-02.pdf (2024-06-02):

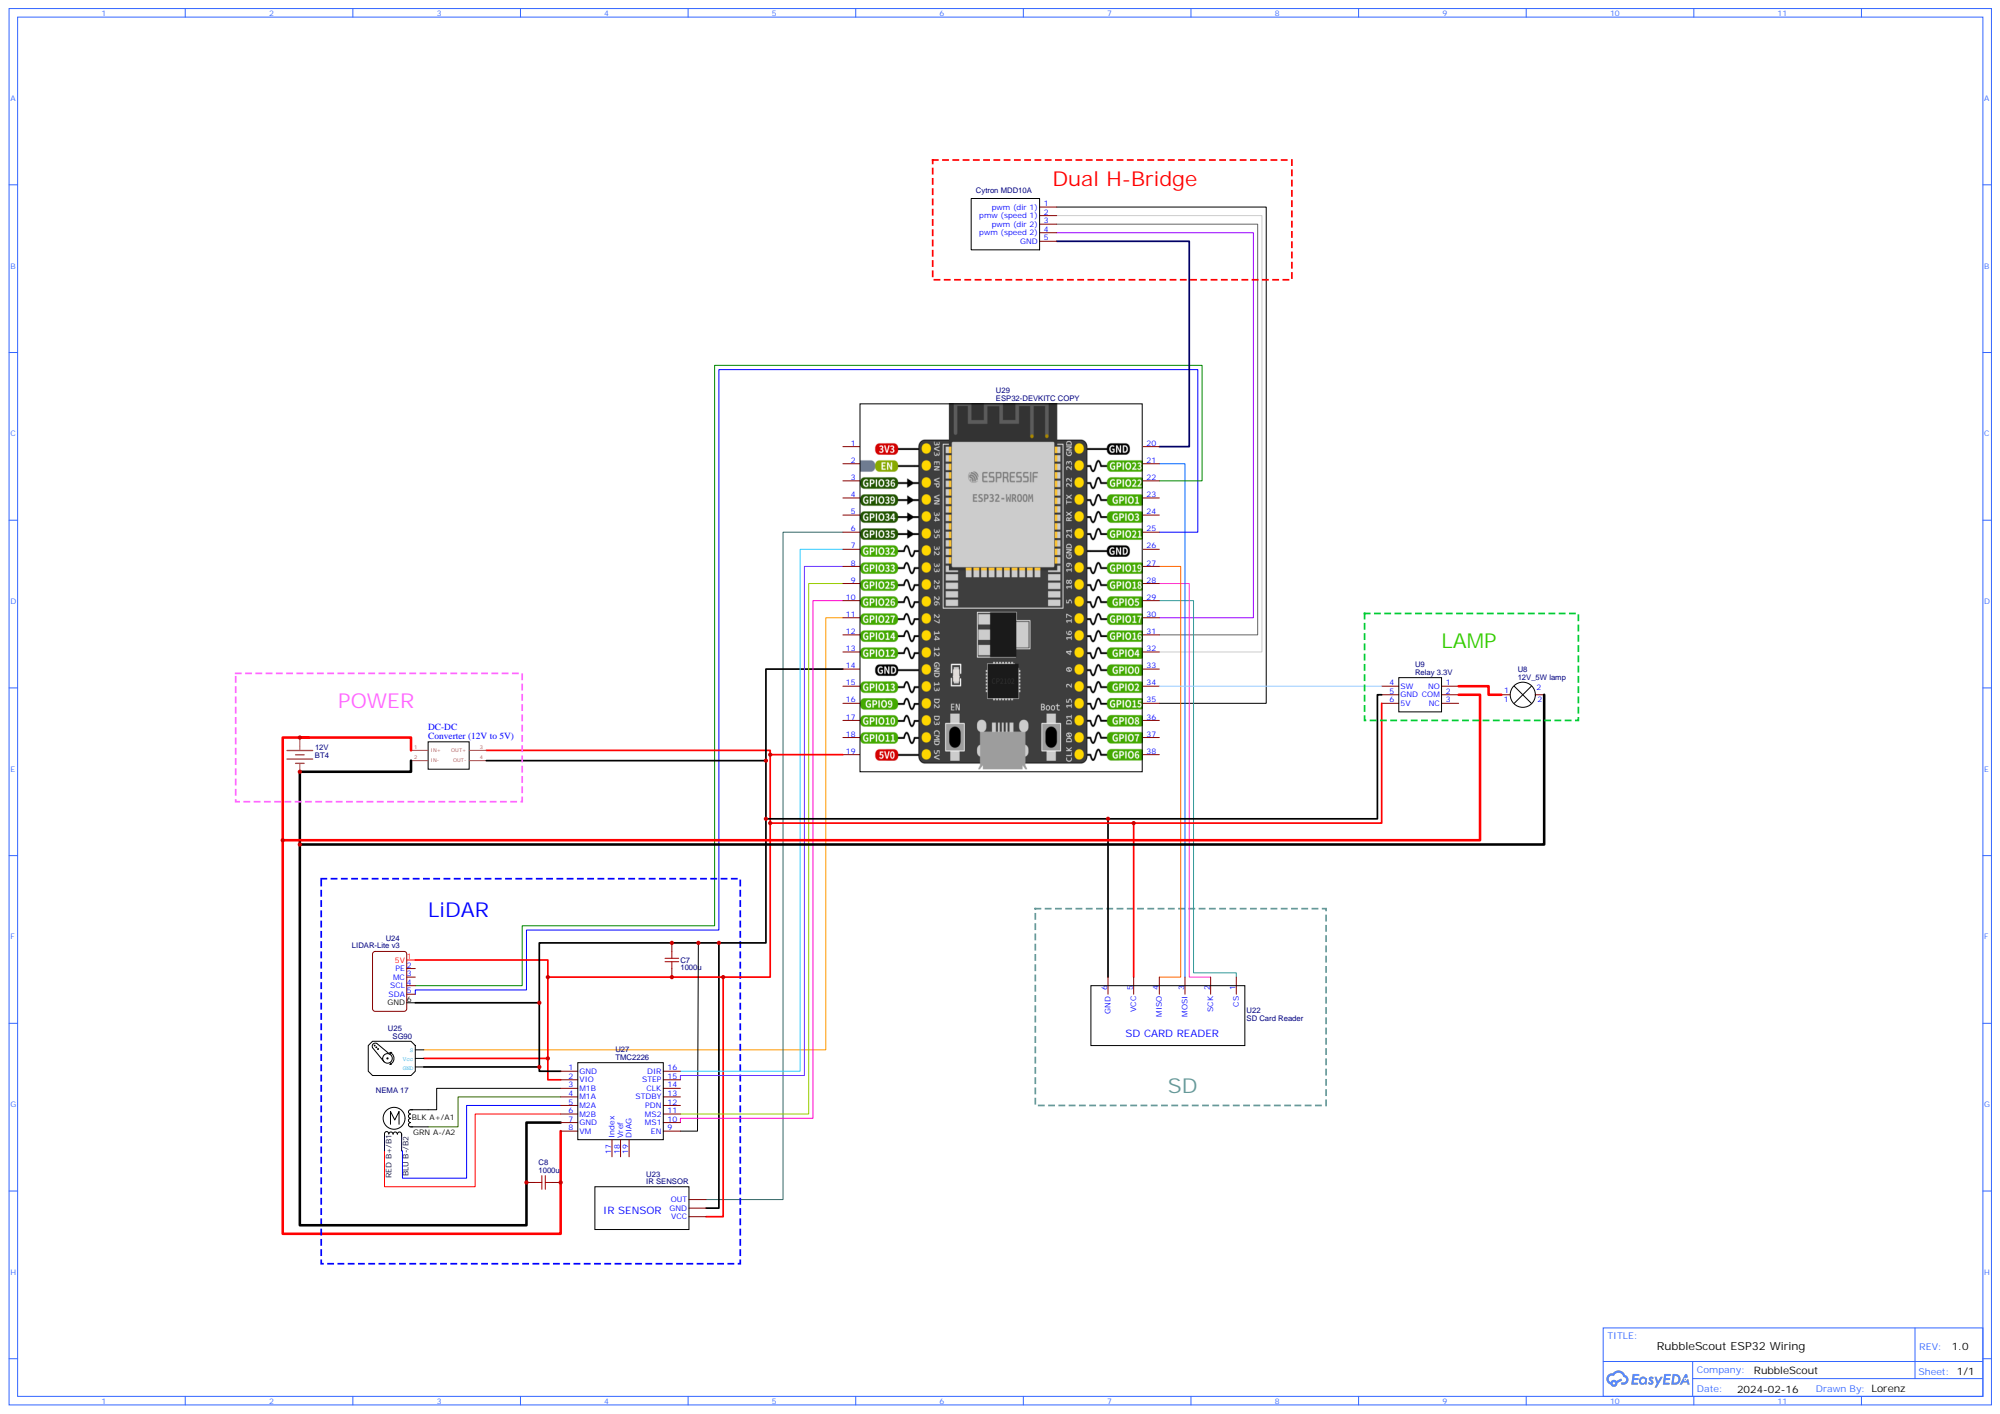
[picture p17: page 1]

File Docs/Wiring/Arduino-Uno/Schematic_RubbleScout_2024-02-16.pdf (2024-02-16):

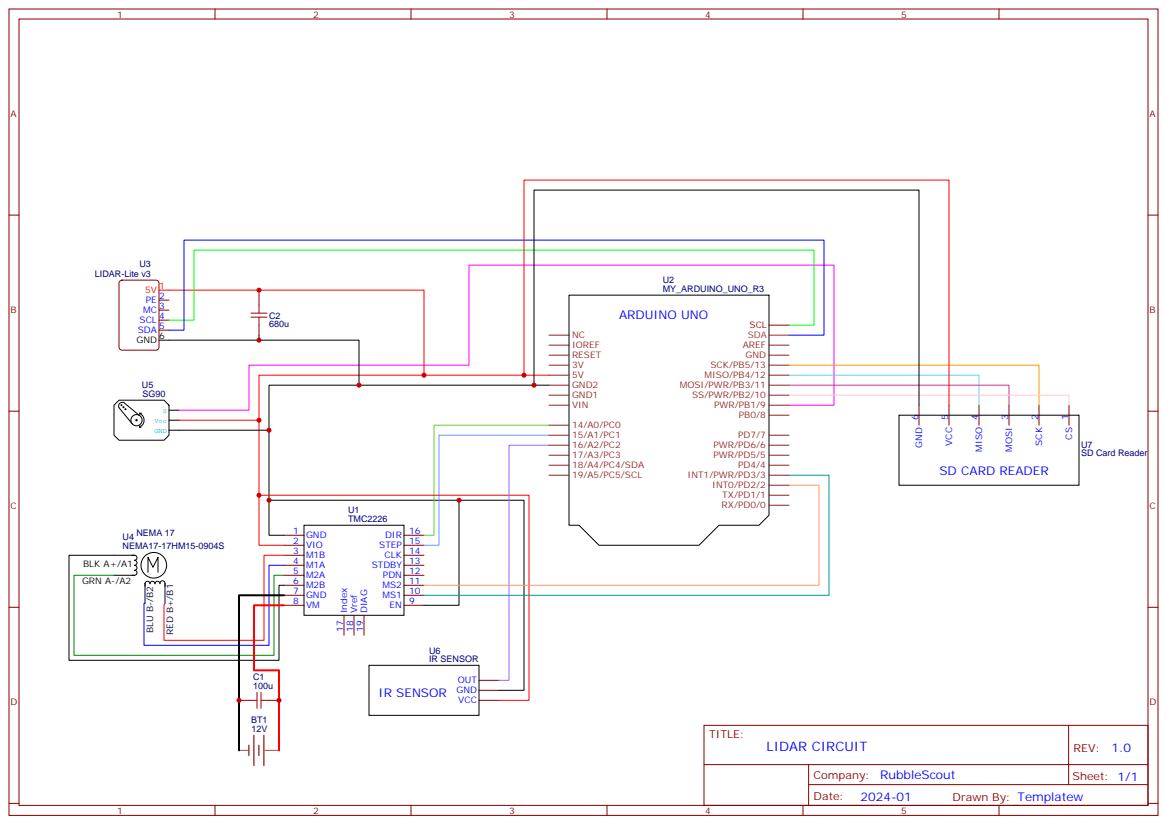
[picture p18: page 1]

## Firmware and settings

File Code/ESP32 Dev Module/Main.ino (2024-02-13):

/*
____/\\\\\\\\\______________________/\\\__________/\\\__________/\\\\\\_________________________/\\\\\\\\\\\_______________________________________________________________        
 __/\\\///////\\\___________________\/\\\_________\/\\\_________\////\\\_______________________/\\\/////////\\\_____________________________________________________________       
  _\/\\\_____\/\\\___________________\/\\\_________\/\\\____________\/\\\______________________\//\\\______\///____________________________________________________/\\\______      
   _\/\\\\\\\\\\\/______/\\\____/\\\__\/\\\_________\/\\\____________\/\\\_________/\\\\\\\\_____\////\\\______________/\\\\\\\\______/\\\\\______/\\\____/\\\___/\\\\\\\\\\\_     
    _\/\\\//////\\\_____\/\\\___\/\\\__\/\\\\\\\\\___\/\\\\\\\\\______\/\\\_______/\\\/////\\\_______\////\\\_________/\\\//////_____/\\\///\\\___\/\\\___\/\\\__\////\\\////__    
     _\/\\\____\//\\\____\/\\\___\/\\\__\/\\\////\\\__\/\\\////\\\_____\/\\\______/\\\\\\\\\\\___________\////\\\_____/\\\___________/\\\__\//\\\__\/\\\___\/\\\_____\/\\\______   
      _\/\\\_____\//\\\___\/\\\___\/\\\__\/\\\__\/\\\__\/\\\__\/\\\_____\/\\\_____\//\\///////_____/\\\______\//\\\___\//\\\_________\//\\\__/\\\___\/\\\___\/\\\_____\/\\\_/\\__  
       _\/\\\______\//\\\__\//\\\\\\\\\___\/\\\\\\\\\___\/\\\\\\\\\____/\\\\\\\\\___\//\\\\\\\\\\__\///\\\\\\\\\\\/_____\///\\\\\\\\___\///\\\\\/____\//\\\\\\\\\______\//\\\\\___ 
        _\///________\///____\/////////____\/////////____\/////////____\/////////_____\//////////_____\///////////_________\////////______\/////_______\/////////________\/////____
*/  

/**
 * @file MotorsDemo.ino
 * @brief MotorsDemo code file for controlling RubbleScout on an ESP32 (basic mouvements).
 * 
 * This file contains the MotorsDemo code for controlling the chassis of a robot using an ESP32 microcontroller. It includes functions for moving the motors, processing commands received via Bluetooth, and setting up the H-Bridge and PWM.
 * 
 * The code uses the BluetoothSerial library to establish a Bluetooth connection with a paired device. It reads data from the Bluetooth module and processes commands in the format "{X:Y}", where X and Y represent the desired speeds for the left and right motors respectively.
 * 
 * The H-Bridge pins and PWM channels are defined at the beginning of the code, and the move() function sets the direction and speed of the motors based on the input values.
 * 
 * This code also includes a failsafe mechanism that stops the motors if the Bluetooth connection is lost.
 * 
 * @author Templatew
 * @date 02-2024
 * @version 1.0
 */

////////////////////////////////////////////////////////////////////////////////////////////////////////////////////////////////////////////////////////////////////////////////////////////////////////////////////////

#include "BluetoothSerial.h"
#include <Wire.h>
// #include <Servo.h>
// #include <LIDARLite.h>
#include <SPI.h>
// #include <SD.h>

////////////////////////////////////////////////////////////////////////////////////////////////////////////////////////////////////////////////////////////////////////////////////////////////////////////////////////

// H-Bridge

#define DIR1 15  // GPIO pin for the right motor direction
#define DIR2 16 // GPIO pin for the left motor direction
#define PW1 4  // GPIO pin for the right motor speed
#define PW2 17  // GPIO pin for the left motor speed

#define LEDC_CHANNEL_0 0 // PWM channel for the right motor
#define LEDC_CHANNEL_1 1 // PWM channel for the left motor
#define LEDC_TIMER_8_BIT 8 // PWM resolution
#define LEDC_BASE_FREQ 5000 


void setupHbridge() {
    pinMode(DIR1, OUTPUT);
    pinMode(DIR2, OUTPUT);
    ledcSetup(LEDC_CHANNEL_0, LEDC_BASE_FREQ, LEDC_TIMER_8_BIT);
    ledcSetup(LEDC_CHANNEL_1, LEDC_BASE_FREQ, LEDC_TIMER_8_BIT);
    ledcAttachPin(PW1, LEDC_CHANNEL_0);
    ledcAttachPin(PW2, LEDC_CHANNEL_1);
}

/**
 * @brief Set the direction and speed of the motors.
 * 
 * This function sets the direction and speed of the motors based on the input values.
 * If the speed is negative, the corresponding motor will rotate in the opposite direction.
 * 
 * @param speedLeft The desired speed for the left motor (-255 to 255).
 * @param speedRight The desired speed for the right motor (-255 to 255).
 */
void move(int speedLeft, int speedRight) {
    // Set the direction of the motors 
    if (speedRight < 0) {
        digitalWrite(DIR1, HIGH);
    } 
    else {
        digitalWrite(DIR1, LOW);
    }

    if (speedLeft < 0) {
        digitalWrite(DIR2, HIGH);
    } 
    else {
        digitalWrite(DIR2, LOW);
    }

    ledcWrite(LEDC_CHANNEL_0, abs(speedRight));
    ledcWrite(LEDC_CHANNEL_1, abs(speedLeft));
}


////////////////////////////////////////////////////////////////////////////////////////////////////////////////////////////////////////////////////////////////////////////////////////////////////////////////////////

// Bluetooth
#define USE_PIN
const char *pin = "1234"; // Change this to a more secure PIN.

String device_name = "ESP32-BT-Slave";
BluetoothSerial SerialBT;

String incomingData = ""; 
bool commandStarted = false; 

void setupBluetooth() {
    SerialBT.begin(device_name); // Bluetooth device name
    // Serial.printf("The device with name \"%s\" is started.\nNow you can pair it with Bluetooth!\n", device_name.c_str());
    #ifdef USE_PIN
        SerialBT.setPin(pin);
        // Serial.println("Using PIN");
    #endif
}

/**
 * @brief Process a command received via Bluetooth.
 * 
 * This function processes a command received via Bluetooth in the format "{X:Y}",
 * where X and Y represent the desired speeds for the left and right motors respectively.
 * It extracts the X and Y values from the command string, converts them to integers,
 * and calculates the corresponding speeds for the motors.
 * The move() function is then called with the calculated speeds.
 * 
 * @param command The command string received via Bluetooth.
 */
void processCommand(String command) {
    int xIndex = command.indexOf('X'); // Find the index of 'X'
    int yIndex = command.indexOf('Y'); // Find the index of 'Y'
    
    if (xIndex != -1 && yIndex != -1) {
        
        String xStr = command.substring(xIndex+1, yIndex);
        String yStr = command.substring(yIndex+1);

        int x = xStr.toInt(); 
        int y = yStr.toInt(); 
        int pwmg;
        int pwmd;
        if (y>0){
            x = -x;
        }
        pwmg = constrain(-y+x, -255, 255);
        pwmd = constrain(-y-x, -255, 255);
        move(pwmg,pwmd);
    }
}


////////////////////////////////////////////////////////////////////////////////////////////////////////////////////////////////////////////////////////////////////////////////////////////////////////////////////////

// Servo

// Servo servo; // Create a servo object to control the pan-tilt mechanism
#define ANGLE_MIN 1000 // Minimum angle for servo in microseconds (0 degrees = 500 microseconds)
#define ANGLE_MAX 1600 // Maximum angle for servo in microseconds (180 degrees = 2500 microseconds)
#define ANGLE_MOY (ANGLE_MAX + ANGLE_MIN) / 2 // Middle angle for servo in microseconds

#define ANGLE_MIN_DEG map(ANGLE_MIN, 500, 2500, 0, 180) // Minimum angle for servo in degrees
#define ANGLE_MAX_DEG map(ANGLE_MAX, 500, 2500, 0, 180) // Maximum angle for servo in degrees

#define RANGE_MICROSECONDS ANGLE_MAX - ANGLE_MIN // Range of servo in microseconds
#define RANGE_DEGREES ANGLE_MAX_DEG - ANGLE_MIN_DEG // Range of servo in degrees

////////////////////////////////////////////////////////////////////////////////////////////////////////////////////////////////////////////////////////////////////////////////////////////////////////////////////////

// Stepper motor

// Stepper motor pins
#define STEP 33
#define DIR 32
#define MS1 26
#define MS2 25

const double STEPS_ANGLE_DEFAULT = 1.8; // Number of degrees per step in default mode
int microsteps = 16; // Number of microsteps per step
double stepsAngle = STEPS_ANGLE_DEFAULT / microsteps; // Number of degrees per step
int stepsPerRev = 360 / stepsAngle; // Number of steps per revolution
#define MAX_DELAY 2000 // Maximum delay between steps in microseconds
#define MIN_DELAY 170 // Minimum delay between steps in microseconds
int delayStepperMotor = 500; // Delay between steps in microseconds

void setupStepper() {
    // Set pin modes
    pinMode(STEP, OUTPUT);
    pinMode(DIR, OUTPUT);
    pinMode(MS1, OUTPUT);
    pinMode(MS2, OUTPUT);
}

void step(int steps) {
    // Set direction
    if (steps < 0) {
        digitalWrite(DIR, HIGH);
    } 
    else {
        digitalWrite(DIR, LOW);
    }
    // Step
    for (int i = 0; i < abs(steps); i++) {
        digitalWrite(STEP, HIGH);
        delayMicroseconds(delayStepperMotor);
        digitalWrite(STEP, LOW);
        delayMicroseconds(delayStepperMotor);
    }
}



void setSpeed(int speed) {
    // Set delay between steps
    delayStepperMotor = map(speed, 0, 100, (MAX_DELAY*8)/microsteps, (MIN_DELAY * 8)/microsteps);
}

void setPrecision(int precision) {
    // Set microsteps
    switch(precision) {
        case 8:
            // 8 microsteps
            microsteps = 8;
            digitalWrite(MS1, LOW);
            digitalWrite(MS2, LOW);
            break;
        case 16:
            // 16 microsteps
            microsteps = 16;
            digitalWrite(MS1, HIGH);
            digitalWrite(MS2, HIGH);
            break;
        case 32:
            // 32 microsteps
            microsteps = 32;
            digitalWrite(MS1, HIGH);
            digitalWrite(MS2, LOW);
            break;
        case 64:
            // 64 microsteps
            microsteps = 64;
            digitalWrite(MS1, LOW);
            digitalWrite(MS2, HIGH);
            break;
        default:
            // Default to 16 microsteps
            microsteps = 16;
            digitalWrite(MS1, HIGH);
            digitalWrite(MS2, HIGH);
            break;
    }
    stepsAngle = STEPS_ANGLE_DEFAULT / microsteps; // Number of degrees per step
    stepsPerRev = 360 / stepsAngle;
    setSpeed(10);
    
}

////////////////////////////////////////////////////////////////////////////////////////////////////////////////////////////////////////////////////////////////////////////////////////////////////////////////////////

// IR sensor
#define IR_THRESHOLD 90 // Threshold for IR sensor

////////////////////////////////////////////////////////////////////////////////////////////////////////////////////////////////////////////////////////////////////////////////////////////////////////////////////////

// SD card
#define FILENAME "data.txt" // Name of file to save data to
// File dataFile; // File to save data to

////////////////////////////////////////////////////////////////////////////////////////////////////////////////////////////////////////////////////////////////////////////////////////////////////////////////////////

//Lidar Lite v3
// LIDARLite myLidarLite;
double cartesian[3]; // Cartesian coordinates

////////////////////////////////////////////////////////////////////////////////////////////////////////////////////////////////////////////////////////////////////////////////////////////////////////////////////////

void setup() {
    Serial.begin(115200);

    // // Bluetooth
    // SerialBT.begin(device_name); // Bluetooth device name
    // Serial.printf("The device with name \"%s\" is started.\nNow you can pair it with Bluetooth!\n", device_name.c_str());
    // #ifdef USE_PIN
    //     SerialBT.setPin(pin);
    //     Serial.println("Using PIN");
    // #endif

    // H-Bridge
    setupHbridge();

    // Bluetooth
    setupBluetooth();

    // Stepper
    setupStepper();

    setPrecision(8);

    setSpeed(100);
}

////////////////////////////////////////////////////////////////////////////////////////////////////////////////////////////////////////////////////////////////////////////////////////////////////////////////////////

void loop() {

    step(1);
    // Read data from the Bluetooth module
    while (SerialBT.available()) {
        char incomingByte = SerialBT.read(); 

        // Check if the command has started or ended
        if (incomingByte == '{') {
            commandStarted = true; 
            incomingData = ""; 
        }
        else if (incomingByte == '}' && commandStarted) {
            commandStarted = false; 
            processCommand(incomingData); 
        } 
        else if (commandStarted) {
            incomingData += incomingByte; 
        }
    }
    // FailSafe if connection is lost
    if (!SerialBT.connected(1000)) {
        move(0,0);
    }
    
}

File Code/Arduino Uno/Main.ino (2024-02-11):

/*
____/\\\\\\\\\______________________/\\\__________/\\\__________/\\\\\\_________________________/\\\\\\\\\\\_______________________________________________________________        
 __/\\\///////\\\___________________\/\\\_________\/\\\_________\////\\\_______________________/\\\/////////\\\_____________________________________________________________       
  _\/\\\_____\/\\\___________________\/\\\_________\/\\\____________\/\\\______________________\//\\\______\///____________________________________________________/\\\______      
   _\/\\\\\\\\\\\/______/\\\____/\\\__\/\\\_________\/\\\____________\/\\\_________/\\\\\\\\_____\////\\\______________/\\\\\\\\______/\\\\\______/\\\____/\\\___/\\\\\\\\\\\_     
    _\/\\\//////\\\_____\/\\\___\/\\\__\/\\\\\\\\\___\/\\\\\\\\\______\/\\\_______/\\\/////\\\_______\////\\\_________/\\\//////_____/\\\///\\\___\/\\\___\/\\\__\////\\\////__    
     _\/\\\____\//\\\____\/\\\___\/\\\__\/\\\////\\\__\/\\\////\\\_____\/\\\______/\\\\\\\\\\\___________\////\\\_____/\\\___________/\\\__\//\\\__\/\\\___\/\\\_____\/\\\______   
      _\/\\\_____\//\\\___\/\\\___\/\\\__\/\\\__\/\\\__\/\\\__\/\\\_____\/\\\_____\//\\///////_____/\\\______\//\\\___\//\\\_________\//\\\__/\\\___\/\\\___\/\\\_____\/\\\_/\\__  
       _\/\\\______\//\\\__\//\\\\\\\\\___\/\\\\\\\\\___\/\\\\\\\\\____/\\\\\\\\\___\//\\\\\\\\\\__\///\\\\\\\\\\\/_____\///\\\\\\\\___\///\\\\\/____\//\\\\\\\\\______\//\\\\\___ 
        _\///________\///____\/////////____\/////////____\/////////____\/////////_____\//////////_____\///////////_________\////////______\/////_______\/////////________\/////____
*/  

/**
 * @file Main.ino
 * @brief Main code file for the RubbleScout project.
 * 
 * This file contains the main code for the RubbleScout project. It includes the necessary libraries, defines the pin configurations, and implements various functions for controlling the hardware components such as the H-bridge, servo, IR sensor, stepper motor, SD card, Bluetooth, and Lidar Lite v3.
 * 
 * @author Templatew
 * @date 02-2024
 * @version 1.0
 */

////////////////////////////////////////////////////////////////////////////////////////////////////////////////////////////////////////////////////////////////////////////////////////////////////////////////////////

// Include the libraries, you'll need to install the LIDARLite by Garmin and SD by Arduino libraries using the library manage in the Arduino IDE.

#include <Arduino.h>
#include <SoftwareSerial.h>
#include <Wire.h>
#include <Servo.h>
#include <LIDARLite.h>
#include <SPI.h>
#include <SD.h>

////////////////////////////////////////////////////////////////////////////////////////////////////////////////////////////////////////////////////////////////////////////////////////////////////////////////////////

// Define the pins for the Arduino Uno R3

// Double H-Bridge pins
#define DIR1 7
#define DIR2 4
#define PWM1 6
#define PWM2 5

// Servo pins
#define SERVO 9

// Stepper motor pins
#define STEP 15
#define DIR 14
#define MS1 3
#define MS2 2

// IR sensor pins
#define IR1 A2

// SD card pins
#define SD_CS 10 // SD card chip select pin

// Bluetooth pins
#define BT_RX 3 // Bluetooth receive pin
#define BT_TX 2 // Bluetooth transmit pin

////////////////////////////////////////////////////////////////////////////////////////////////////////////////////////////////////////////////////////////////////////////////////////////////////////////////////////

// Define variables

// Servo
Servo servo;
#define ANGLE_MIN 1000 // Minimum angle for servo in microseconds (0 degrees = 500 microseconds)
#define ANGLE_MAX 1600 // Maximum angle for servo in microseconds (180 degrees = 2500 microseconds)
#define ANGLE_MOY (ANGLE_MAX + ANGLE_MIN) / 2 // Middle angle for servo in microseconds

#define ANGLE_MIN_DEG map(ANGLE_MIN, 500, 2500, 0, 180) // Minimum angle for servo in degrees
#define ANGLE_MAX_DEG map(ANGLE_MAX, 500, 2500, 0, 180) // Maximum angle for servo in degrees

#define RANGE_MICROSECONDS ANGLE_MAX - ANGLE_MIN // Range of servo in microseconds
#define RANGE_DEGREES ANGLE_MAX_DEG - ANGLE_MIN_DEG // Range of servo in degrees

// Stepper motor
const double STEPS_ANGLE_DEFAULT = 1.8; // Number of degrees per step in default mode
int microsteps = 16; // Number of microsteps per step
double stepsAngle = STEPS_ANGLE_DEFAULT / microsteps; // Number of degrees per step
int stepsPerRev = 360 / stepsAngle; // Number of steps per revolution
#define MAX_DELAY 2000 // Maximum delay between steps in microseconds
#define MIN_DELAY 500 // Minimum delay between steps in microseconds
int delayStepperMotor = 500; // Delay between steps in microseconds

// IR sensor
#define IR_THRESHOLD 90 // Threshold for IR sensor

// SD card
#define FILENAME "data.txt" // Name of file to save data to
File dataFile; // File to save data to

//Lidar Lite v3
LIDARLite myLidarLite;
double cartesian[3]; // Cartesian coordinates

// Bluetooth
SoftwareSerial BT(BT_RX, BT_TX); // RX, TX

////////////////////////////////////////////////////////////////////////////////////////////////////////////////////////////////////////////////////////////////////////////////////////////////////////////////////////

// Define functions

// H-bridge

void setupHbridge() {
    // Set pin modes
    pinMode(DIR1, OUTPUT);
    pinMode(DIR2, OUTPUT);
    pinMode(PWM1, OUTPUT);
    pinMode(PWM2, OUTPUT);

    // Force STOP
    analogWrite(PWM1, 0);
    analogWrite(PWM2, 0);
}

void move(int speedLeft, int speedRight){
    // Set right motor direction based on speed
    if (speedRight < 0) {
        digitalWrite(DIR1, HIGH);
    } 
    else {
        digitalWrite(DIR1, LOW);
    }
    // Set left motor direction based on speed
    if (speedLeft < 0) {
        digitalWrite(DIR2, HIGH);
    } 
    else {
        digitalWrite(DIR2, LOW);
    }
    // Set motor speeds
    analogWrite(PWM1, abs(speedRight));
    analogWrite(PWM2, abs(speedLeft));
}

// Servo

void setupServo() {
    // Set pin mode
    pinMode(SERVO, OUTPUT);
    // Attach servo
    servo.attach(SERVO, ANGLE_MIN, ANGLE_MAX);
    // Set servo to middle angle
    servo.writeMicroseconds(ANGLE_MOY);
}

void setAngleServo(int microseconds) {
    // Set servo angle
    servo.writeMicroseconds(microseconds);
}

double degreesToRadians(int degrees) {
    // Convert degrees to radians
    return degrees * PI / 180;
}

double microsecondsToDegrees(int microseconds) {
    // Convert microseconds to degrees
    return map(microseconds, ANGLE_MIN, ANGLE_MAX, ANGLE_MIN_DEG, ANGLE_MAX_DEG);
}

double microsecondsToRadians(int microseconds) {
    // Convert microseconds to radians
    return degreesToRadians(microsecondsToDegrees(microseconds));
}

// Ir sensor

void setupIrSensor() {
    // Set pin mode
    pinMode(IR1, INPUT);
}

int readIrSensor() {
    // Return IR sensor value
    return analogRead(IR1);
}

bool isObstacle() {
    // Return true if obstacle detected
    return readIrSensor() < IR_THRESHOLD;
}

// Stepper motor
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

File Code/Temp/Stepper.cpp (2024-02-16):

/*
____/\\\\\\\\\______________________/\\\__________/\\\__________/\\\\\\_________________________/\\\\\\\\\\\_______________________________________________________________        
 __/\\\///////\\\___________________\/\\\_________\/\\\_________\////\\\_______________________/\\\/////////\\\_____________________________________________________________       
  _\/\\\_____\/\\\___________________\/\\\_________\/\\\____________\/\\\______________________\//\\\______\///____________________________________________________/\\\______      
   _\/\\\\\\\\\\\/______/\\\____/\\\__\/\\\_________\/\\\____________\/\\\_________/\\\\\\\\_____\////\\\______________/\\\\\\\\______/\\\\\______/\\\____/\\\___/\\\\\\\\\\\_     
    _\/\\\//////\\\_____\/\\\___\/\\\__\/\\\\\\\\\___\/\\\\\\\\\______\/\\\_______/\\\/////\\\_______\////\\\_________/\\\//////_____/\\\///\\\___\/\\\___\/\\\__\////\\\////__    
     _\/\\\____\//\\\____\/\\\___\/\\\__\/\\\////\\\__\/\\\////\\\_____\/\\\______/\\\\\\\\\\\___________\////\\\_____/\\\___________/\\\__\//\\\__\/\\\___\/\\\_____\/\\\______   
      _\/\\\_____\//\\\___\/\\\___\/\\\__\/\\\__\/\\\__\/\\\__\/\\\_____\/\\\_____\//\\///////_____/\\\______\//\\\___\//\\\_________\//\\\__/\\\___\/\\\___\/\\\_____\/\\\_/\\__  
       _\/\\\______\//\\\__\//\\\\\\\\\___\/\\\\\\\\\___\/\\\\\\\\\____/\\\\\\\\\___\//\\\\\\\\\\__\///\\\\\\\\\\\/_____\///\\\\\\\\___\///\\\\\/____\//\\\\\\\\\______\//\\\\\___ 
        _\///________\///____\/////////____\/////////____\/////////____\/////////_____\//////////_____\///////////_________\////////______\/////_______\/////////________\/////____
*/ 
/** 
 * @file Stepper.cpp
 * @brief Implementation of the Stepper class
 * 
 * This file contains the implementation of the Stepper class, which provides control over a stepper motor.
 * 
 * @author Templatew
 * @date 02-2024
 * @version 1.0
 */

#include "Stepper.h"
#include <Arduino.h>

Stepper::Stepper(){}

void Stepper::begin(){
    pinMode(this->_STEP, OUTPUT);
    pinMode(this->_DIR, OUTPUT);
    pinMode(this->_MS1, OUTPUT);
    pinMode(this->_MS2, OUTPUT);
}

void Stepper::setSpeed(int speed){
    this->_delayStepperMotor = map(speed, 0, 100, (this->_MAX_DELAY*8)/this->_microsteps, (this->_MIN_DELAY * 8)/this->_microsteps);
}

void Stepper::setMicrosteps(int microsteps){
    // Set microsteps
    this->_microsteps = microsteps;
    switch(microsteps) {
        case 8:
            digitalWrite(this->_MS1, LOW);
            digitalWrite(this->_MS2, LOW);
            break;
        case 16:
            digitalWrite(this->_MS1, HIGH);
            digitalWrite(this->_MS2, HIGH);
            break;
        case 32:
            digitalWrite(this->_MS1, HIGH);
            digitalWrite(this->_MS2, LOW);
            break;
        case 64:
            digitalWrite(this->_MS1, LOW);
            digitalWrite(this->_MS2, HIGH);
            break;
        default:
        // Default to 16 microsteps
            digitalWrite(this->_MS1, HIGH);
            digitalWrite(this->_MS2, HIGH);
            break;
    }
    this->_stepsAngle = this->_STEP_ANGLE_DEFAULT / this->_microsteps;
    this->_stepsPerRev = 360 / this->_stepsAngle;
    this->_delayStepperMotor = map(50, 0, 100, (this->_MAX_DELAY*8)/this->_microsteps, (this->_MIN_DELAY * 8)/this->_microsteps);
}

void Stepper::step(){
    digitalWrite(this->_DIR, HIGH);
    digitalWrite(this->_STEP, HIGH);
    delayMicroseconds(this->_delayStepperMotor);
    digitalWrite(this->_STEP, LOW);
    delayMicroseconds(this->_delayStepperMotor);

    this->_currentStep++;
    if(this->_currentStep == this->_stepsPerRev){
        this->_currentStep = 0;
    }
}

int Stepper::getMicrosteps(){
    return this->_microsteps;
}

double Stepper::getStepsAngle(){
    return this->_stepsAngle;
}

int Stepper::getStepsPerRev(){
    return this->_stepsPerRev;
}

double Stepper::getCurrentAngle(){
    return this->_currentStep * this->_stepsAngle;
}
